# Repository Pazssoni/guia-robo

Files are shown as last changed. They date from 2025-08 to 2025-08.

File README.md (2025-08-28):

# BEMO - Bloco Educacional Modular Open-Source

Logo do BEMO

Bem-vindo ao repositório oficial do BEMO, um robô educacional de baixo custo, modular e de código aberto, projetado para democratizar o ensino de STEAM (Ciência, Tecnologia, Engenharia, Artes e Matemática) em escolas e ambientes de aprendizado.

Este projeto foi desenvolvido como um Trabalho de Conclusão de Curso em Engenharia de Computação no Instituto Federal Fluminense (IFF) por Bruno Alves Pesse Libardi e Maurício Santos Passoni.

**[Acesse o Guia Interativo Completo aqui!](https://guia-robo.vercel.app/)**

---

## 🎯 Sobre o Projeto

A robótica educacional é uma ferramenta poderosa, mas seu alto custo é uma barreira significativa para escolas públicas. O BEMO foi criado para ser uma solução acessível e replicável, com um custo de montagem aproximadamente 25 vezes menor que os kits comerciais de mercado.

### ✨ Principais Características
* ** baixo Custo:** Construído com componentes eletrônicos acessíveis, com um custo total estimado em menos de R$ 210,00.
* ** Modular:** Possui um sistema de módulos intercambiáveis (Sumô, Artista, Construtor LEGO) que se adaptam a diferentes atividades pedagógicas.
* ** Open-Source:** Todo o projeto, do hardware ao software, é de código aberto, permitindo que qualquer pessoa possa montar, modificar e aprimorar o BEMO.
* ** Impressão 3D:** O chassi e os módulos são projetados para serem fabricados em qualquer impressora 3D com filamento PLA, incentivando a autonomia e a cultura maker.
* ** Programação Acessível:** Utiliza a plataforma **mBlock**, baseada em blocos, que facilita o aprendizado de lógica de programação para iniciantes.

---

## 🛠️ Como Montar o seu Próprio BEMO

Para replicar o projeto, siga os passos abaixo.

### 1. Lista de Materiais (Bill of Materials)

A lista completa de componentes eletrônicos, parafusos e a bateria necessária pode ser encontrada no **[Guia de Montagem em PDF](./Guia_PDF/Guia_Montagem_BEMO.pdf)**, que está neste repositório.

### 2. Arquivos para Impressão 3D

Todas as peças do chassi e os módulos intercambiáveis estão disponíveis em formato `.STL` na pasta **`/Arquivos_Impressao_3D`** deste repositório.

* **Material Recomendado:** Filamento PLA
* **Configuração Sugerida:** Altura de camada de 0.2mm, com suportes ativados.

### 3. Guia de Montagem

A montagem do hardware é detalhada passo a passo em nossos guias:
* **Guia Interativo (Recomendado):** [https://guia-robo.vercel.app](https://guia-robo.vercel.app) - Inclui vídeos e uma experiência mais dinâmica.
* **Guia em PDF:** Disponível na pasta **`/Guia`**.

### 4. Configuração do Ambiente de Programação (mBlock)

1.  **Instale o mBlock:** Baixe a versão para PC no site oficial: [mblock.cc](https://mblock.cc/pages/downloads).
2.  **Adicione o Dispositivo:** Na aba "Dispositivos", procure e adicione o **"Arduino Nano"**.
3.  **Instale as Extensões:** No "Centro de Extensões", pesquise e adicione as duas extensões necessárias:
    * `Easy Motor Driver`
    * `TCRT5000 IR`
4.  **Comece a Programar!** As atividades práticas e os códigos de exemplo estão no Capítulo 7 dos guias (interativo e PDF).

---

## 📁 Estrutura do Repositório

* **/Arquivos_Impressao_3D:** Contém todos os arquivos `.STL` para imprimir o BEMO.
* **/Guia_PDF:** Contém a versão em PDF do guia completo de montagem e programação.
* **index.html:** Código-fonte do guia interativo online.
* **README.md:** Este arquivo que você está lendo.

---

## 📜 Citação

Se você utilizar este projeto em seu trabalho, por favor, cite-o da seguinte forma:

LIBARDI, B. A. P.; PASSONI, M. S. **BEMO (Bloco Educacional Modular Open-Source): um robô educacional de baixo custo para o ensino de STEAM.** Trabalho de Conclusão de Curso (Graduação em Engenharia de Computação) – Instituto Federal Fluminense, Bom Jesus do Itabapoana, 2025.

---

## 👨‍💻 Autores

* **Bruno Alves Pesse Libardi**
* **Maurício Santos Passoni**

Agradecemos o apoio dos nossos orientadores, Ianne Lima Nogueira e Anderson de Souza Lima.

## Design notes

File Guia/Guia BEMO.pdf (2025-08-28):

## Guia Completo do BEMO: Montagem, Programação e Exploração Criativa

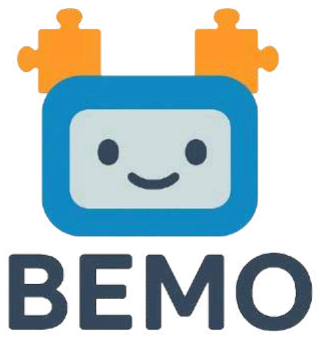
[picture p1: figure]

## Autores: Bruno Libardi e Maurício Passoni

### Prefácio: Uma Aventura no Mundo da Robótica

Bem-vindo ao fascinante universo da robótica! O guia que tem em mãos é mais do que um manual de instruções; é um convite para uma jornada de descoberta, criação e aprendizado. Ao longo das próximas páginas, será possível transformar um conjunto de peças impressas em 3D e componentes eletrônicos em um robô funcional e inteligente. Este processo foi desenhado para ser uma aventura gratificante, onde cada parafuso apertado e cada bloco de código encaixado representam um passo em direção a uma nova compreensão sobre como a tecnologia funciona.
E para começar nossa jornada, vamos conhecer nosso robô pelo nome: ele se chama BEMO! O nome é uma sigla para Bloco Educacional Modular Open-Source, que resume tudo o que ele representa: uma ferramenta de aprendizado baseada em blocos de programação, com peças que se encaixam e um projeto totalmente aberto para quem quiser montar e aprimorar.

Por que Robótica?
A robótica educacional é uma poderosa ferramenta que prepara jovens para um futuro cada vez mais tecnológico. Ensinar e aprender robótica vai muito além de construir e programar máquinas; trata-se de desenvolver habilidades fundamentais para o século XXI. Através de atividades práticas e envolventes, os participantes exercitam o raciocínio lógico, a capacidade de resolver problemas complexos, a criatividade para encontrar novas soluções e o trabalho em equipe para alcançar objetivos comuns. Ao construir este robô, os alunos não estão apenas "brincando", mas se engajando ativamente em conceitos de ciência, tecnologia, engenharia, artes e matemática (STEAM), preparando-se para os desafios do futuro de forma interativa.

Objetivos Deste Guia
Ao concluir a leitura e as atividades propostas neste guia, qualquer utilizador, seja professor ou aluno, será capaz de:

### 1. Montar o BEMO a partir de peças impressas em 3D e componentes

eletrônicos, compreendendo a função de cada parte.

### 2. Identificar e entender o papel dos componentes principais: o "cérebro"

(microcontrolador), os "músculos" (motores) e os "sentidos" (sensores).

### 3. Aprender os fundamentos da programação visual baseada em blocos

utilizando o software mBlock.

### 4. Executar missões práticas e desafios que darão vida, propósito e

personalidade ao BEMO.
Uma Nota para Professores e Alunos
Este guia foi criado com um princípio em mente: qualquer pessoa pode aprender robótica. Não é necessário nenhum conhecimento prévio em eletrônica, programação ou impressão 3D. Cada capítulo foi estruturado para apresentar os conceitos de forma clara e passo a passo. O erro não deve ser visto como um fracasso, mas como uma parte essencial do processo de "aprender fazendo" (learning by doing).

### 2 Encoraja-se a

experimentação, a curiosidade e a colaboração. Juntos, professores e alunos podem transformar este projeto numa experiência de aprendizado inesquecível.

Prefere Aprender com Vídeos? Conheça nosso Guia Interativo!

Para uma experiência de montagem ainda mais visual e detalhada, criamos um Guia Online Interativo. Além de todo o conteúdo que você encontra aqui, a versão online te dá acesso a vídeos tutoriais para as principais etapas, mostrando o passo a passo em ação.

Acesse a qualquer momento em: https://guia-robo.vercel.app

Conectando o BEMO à Sala de Aula: Uma Ferramenta para a BNCC

Professor, uma das maiores potências do BEMO é sua capacidade de se conectar a diferentes áreas do conhecimento, funcionando como uma ponte entre a teoria e a prática. Este robô não é apenas uma ferramenta para ensinar programação; ele foi pensado para desenvolver competências e habilidades previstas na Base Nacional Comum Curricular

(BNCC) de forma lúdica e interdisciplinar. Ao trabalhar com o BEMO, os estudantes são incentivados a exercitar o Pensamento Científico, Crítico e Criativo (Competência Geral 2) e a Cultura Digital (Competência Geral 5), aprendendo não apenas a consumir tecnologia, mas a criá-la.

Como Conectar as Matérias com as Atividades do Guia?

As atividades práticas propostas neste guia, especialmente com o uso dos módulos intercambiáveis, abrem portas para explorar conteúdos de diversas matérias. Aqui estão algumas ideias baseadas nas habilidades da BNCC:

- Matemática:
- Atividade Sugerida: Usar o "Módulo Artista Robótico" para desenhar figuras geométricas.
- Conexão com a BNCC: Os alunos aplicarão na prática conceitos de geometria, ângulos e plano cartesiano para programar os desenhos. Eles também podem usar álgebra para otimizar os códigos com laços e variáveis.
- Ciências da Natureza:
- Atividade Sugerida: Realizar um combate com o "Módulo Lutador de Sumô".
- Conexão com a BNCC: É a oportunidade perfeita para discutir e investigar conceitos de Física como força, atrito, torque e centro de gravidade de forma experimental.
- Ciências Humanas:
- Atividade Sugerida: Programar o robô para seguir uma rota desenhada em um mapa ou maquete.
- Conexão com a BNCC: Em Geografia, os alunos podem trabalhar com a elaboração e interpretação de mapas, usando o robô para representar trajetos ou fluxos.
- Linguagens:
- Atividade Sugerida: Criar desenhos e padrões artísticos com o "Módulo Artista Robótico".
- Conexão com a BNCC: Em Artes, os estudantes utilizam a programação como uma nova forma de expressão para produzir repertórios artísticos. Em Língua Portuguesa, podem ser incentivados a criar um "diário de bordo" do projeto, relatando os experimentos e desafios.

Esses são apenas pontos de partida. Encorajamos você, professor, a usar sua criatividade para integrar o BEMO aos seus planos de aula, transformando o aprendizado em uma experiência "mão na massa", engajadora e alinhada às demandas educacionais do século XXI.

### Antes de Começar: Checklist de Materiais e Ferramentas

Para garantir que a jornada de montagem seja fluida e sem interrupções, é fundamental preparar todos os componentes e ferramentas com antecedência. Utilize esta página como um checklist para organizar seu espaço de trabalho.

Componentes do BEMO

Esta é a lista completa de peças que darão vida, movimento e sentidos ao seu robô.

- Eletrônica Central:
- 1x Microcontrolador Arduino Nano V3.0
- 1x Placa de Expansão (Shield) Nano IO
- Sistema de Locomoção:
- 2x Motores DC com Caixa de Redução
- 2x Rodas com Pneu de Borracha
- 1x Roda Livre (Roda Boba / Caster Wheel)
- Sensores (Os Sentidos do Robô):
- 1x Sensor de Distância a Laser (VL53L0X)
- 1x Placa com 5 Sensores de Linha (TCRT5000)
- Controle e Energia:
- 1x Módulo Driver Ponte H Dupla (L9110S)
- 1x Bateria de Lítio-Íon 18650 (Pack 7.4V, 3300mAh)

- Conexão e Fixação:
- 17x Jumpers Fêmea-Fêmea
- 1x Jumper Macho-Fêmea
- 1x Jumper Macho-Macho (para solda no pino VIN)
- 12x Parafusos M3x6mm
- 4x Porcas M3
- Estrutura (Impressão 3D):
- 1x Chassi Principal Impresso em PLA
- Módulos Intercambiáveis (Básico, Sumô, etc.)

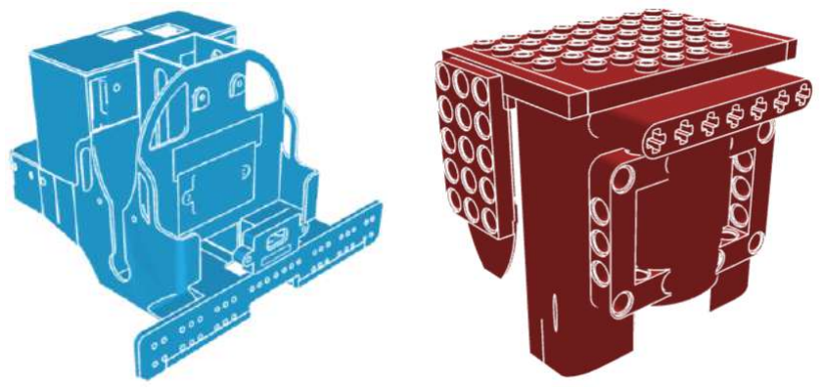
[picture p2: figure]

Ferramentas Necessárias

Estas são as ferramentas que você precisará para a montagem. Lembre-se que algumas delas devem ser manuseadas por um adulto ou supervisor.

- Ferramentas de Montagem:
- Chave Phillips (tamanho pequeno, compatível com parafusos M3)
- Alicate de bico fino (para remover suportes da impressão 3D)
- Equipamentos de Segurança:
- Óculos de Proteção (Obrigatório): Essencial durante a remoção dos suportes da peça impressa para proteger os olhos de fragmentos de plástico.
- Para o Supervisor (Uso Adulto):
- Ferro de Solda e Estanho (para a fixação dos fios nos motores e no pino VIN do shield)
- Estilete (para acabamento fino e remoção de rebarbas)
- Opcional (para Acabamento):
- Lixas d'água (granulação 240, 400 e 800) para um acabamento mais liso nas peças.

### Navegue pelos Capítulos

Capítulo 5: Personalidade e Função - Explorando os Módulos Intercambiáveis...

### Capítulo 1: Dando Vida ao Chassi - A Magia da Impressão 3D

A primeira etapa para construir o BEMO é fabricar o seu "esqueleto", o chassi. Utilizando a tecnologia de impressão 3D, é possível transformar um arquivo digital num objeto físico e funcional.

Obtendo os Arquivos
Para começar, é necessário baixar os arquivos de modelo 3D, eles estão no formato .STL. Estes arquivos contêm as informações geométricas que a impressora 3D utilizará para construir as peças camada por camada. O link para o download dos arquivos do chassi será disponibilizado a seguir.

Preparando para a Impressão
Antes de iniciar a impressão, algumas preparações são necessárias no software "fatiador" (slicer), como o Ultimaker Cura.
- Requisitos da Impressora: É preciso uma impressora 3D com uma mesa de impressão de dimensões suficientes para a peça do chassi. O material recomendado para este projeto é o filamento PLA (Ácido Polilático), por ser fácil de imprimir e seguro para ambientes educacionais.
Por que usamos o PLA?
Embora existam outros materiais como ABS e PETG, o PLA foi escolhido por ser o mais fácil e seguro de imprimir em qualquer impressora 3D, mesmo em modelos abertos e sem mesa aquecida, condições comuns em escolas. Ele oferece a resistência necessária para o robô e é biodegradável.
- Configurações do Fatiador: Para um bom equilíbrio entre velocidade e qualidade, recomenda-se uma altura de camada de 0.2 mm. Um ponto crucial é a ativação de suportes.

Pós-impressão: O Trabalho do Artesão

Após a conclusão da impressão, a peça não está pronta para uso imediato. A fase de pós-processamento é fundamental para garantir não apenas uma boa aparência, mas principalmente o encaixe correto dos componentes eletrônicos e mecânicos.
- Passo 1: Remoção dos Suportes
A peça impressa sairá da impressora com as estruturas de suporte ainda presas, semelhante ao que é visto na Imagem 1. A remoção deve ser feita com cuidado.
- Ferramentas: Utilize um alicate de bico fino ou uma pequena espátula para quebrar e remover os suportes maiores.
- Segurança: Este processo pode gerar pequenos fragmentos de plástico afiados. É altamente recomendado o uso de óculos de proteção para evitar acidentes. A remoção deve ser feita de forma lenta e controlada para não danificar a peça principal.
- Passo 2: Limpeza e Acabamento
É comum que a peça apresente pequenas rebarbas ou fios finos de plástico (conhecidos como "stringing"). Estes podem ser removidos cuidadosamente com um estilete (por um adulto) ou com os dedos.
- Passo 3 (Opcional): Lixamento para um Acabamento Superior
Este passo é opcional e recomendado caso você deseje obter uma aparência mais lisa e profissional para o seu robô, ou se notar que o encaixe de alguma peça está muito justo. O lixamento ajuda a remover as linhas de camada visíveis da impressão 3D e a realizar ajustes finos nas dimensões dos encaixes, garantindo que os componentes se acoplem perfeitamente.
- Técnica: Para o PLA, recomenda-se o lixamento úmido. Molhar a lixa e a peça com água ajuda a resfriar a superfície, evitando que o atrito excessivo derreta o plástico.
- Granulação: Inicie com uma lixa de granulação mais grossa (ex:
240) para remover as imperfeições maiores. Em seguida, avance para granulações mais finas (ex: 400, 800 ou superior) para obter uma superfície lisa. O objetivo é refinar a estética e corrigir pequenas imperfeições da impressão que possam dificultar o encaixe dos motores, sensores e placas.

### Capítulo 2: Os Primeiros Passos - Montando a Mobilidade

Com o chassi pronto, é hora de dar ao BEMO a capacidade de se mover. Neste capítulo, serão instalados os componentes responsáveis pela mobilidade: a roda livre e os motores.O Terceiro Ponto de Apoio
Para que o robô se equilibre e se mova suavemente, ele utiliza duas rodas motorizadas e um terceiro ponto de apoio. Este apoio é uma roda livre (também chamada de caster wheel ou esfera de apoio).
- Instalação: Localize os furos de montagem na parte inferior e frontal do chassi. Posicione a roda livre sobre os furos e fixe-a utilizando dois parafusos de tamanho apropriado com suas respectivas porcas. Aperte firmemente para que não haja folgas.

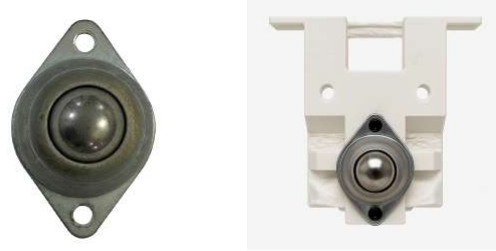
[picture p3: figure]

Instalando os "Músculos" - Os Motores DC
Os "músculos" do BEMO são os dois motores de corrente contínua (DC) com caixa de redução. A caixa de redução (a parte amarela visível na Imagem 4) diminui a velocidade do motor, mas aumenta sua força (torque), permitindo que o robô se mova com precisão e força.
- Encaixe: Insira cada motor nos seus respectivos suportes laterais no chassi. O design do chassi deve permitir um encaixe justo. Empurre os motores até o fim.
- Fixação: Se notar alguma folga, utilize os furos de fixação laterais para inserir pequenos parafusos que prenderão o motor firmemente contra o chassi. Um motor solto pode causar vibrações e imprecisão no movimento. A Imagem 4 mostra um motor já encaixado lateralmente.
- Atenção, Professor! Os fios elétricos precisam ser conectados aos terminais metálicos na parte traseira de cada motor. Esta conexão é mais robusta e confiável quando feita com solda. Recomenda-se que este passo seja realizado por um professor ou adulto com experiência em soldagem antes da aula, para garantir a segurança dos alunos e a qualidade da conexão elétrica.

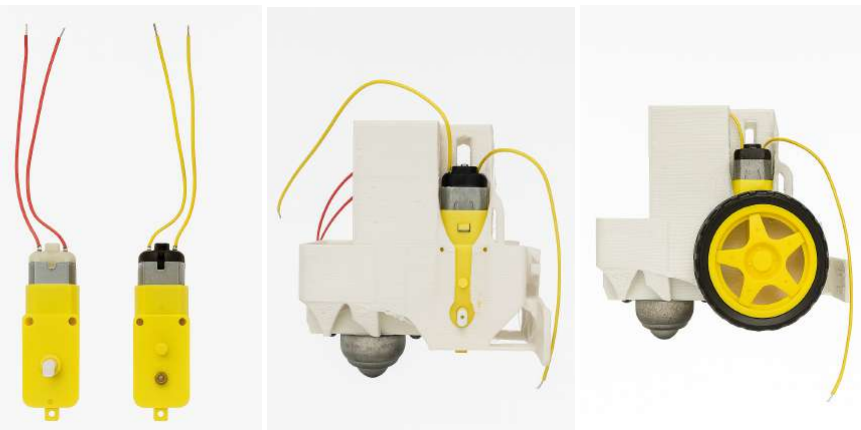
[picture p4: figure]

A Ponte para o Controle - Conectando a Ponte H
O cérebro do robô (Arduino) não consegue fornecer energia suficiente para mover os motores diretamente. Além disso, ele precisa de uma forma de dizer aos motores para girarem para frente ou para trás. A Ponte H resolve ambos os problemas.

O que é uma Ponte H?
Imagine a Ponte H como um conjunto de quatro interruptores inteligentes para cada motor. Ao combinar como estes interruptores são ligados ou desligados, a Ponte H pode direcionar a energia da bateria para fazer o motor girar no sentido horário ou anti-horário. É o componente que "traduz" os comandos de baixo sinal do Arduino em movimento de alta potência para os motores.9
- Conexão dos Motores: Antes de instalar a Ponte H no chassi, conecte os dois fios de cada motor aos terminais de saída da placa. Geralmente, estes terminais são identificados como OUT1 e OUT2 para o motor esquerdo, e OUT3 e OUT4 para o motor direito. A ordem exata determinará o sentido de rotação "padrão", mas isso pode ser corrigido posteriormente na programação.
- Instalação no Chassi: Após conectar os fios dos motores, encaixe a placa da Ponte H no local designado na parte frontal do robô. Os fios de entrada da Ponte H (que virão do Arduino) devem ficar acessíveis. A montagem nesta sequência — conectar os motores à Ponte H primeiro e depois fixá-la — é muito mais simples do que tentar conectar os fios com a placa já no lugar.

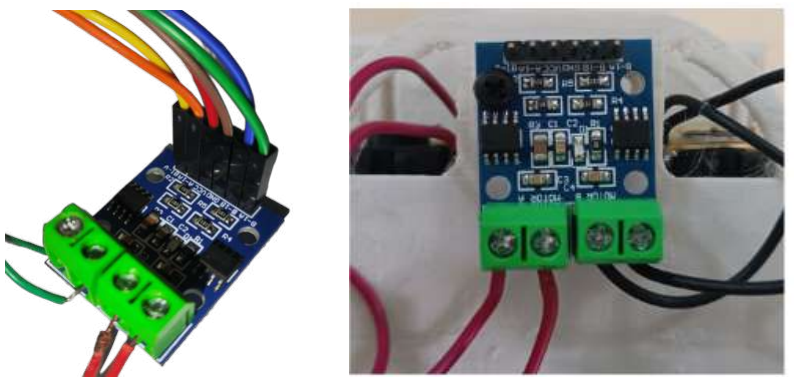
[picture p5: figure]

### Capítulo 3: O Cérebro da Operação - Instalando a Eletrônica Central

Agora que o robô tem um corpo e músculos, é hora de instalar o seu cérebro: o microcontrolador Arduino Nano e seu shield de expansão.

Conheça o Cérebro: O Arduino Nano
O Arduino é uma plataforma de prototipagem eletrônica de código aberto. A placa Arduino Nano é o "cérebro" do nosso robô. É um pequeno computador que pode ser programado para ler informações do ambiente através de sensores e controlar atuadores, como os motores, para interagir com o mundo físico.

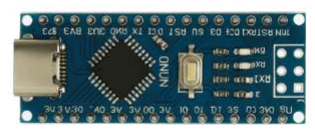
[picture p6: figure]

O Escudo Protetor e Conector: O Shield
Um "shield" é uma placa de circuito impresso que se encaixa sobre o Arduino para expandir suas capacidades. Neste projeto, o shield facilita enormemente a conexão de todos os sensores e da Ponte H, organizando as portas e fornecendo pinos de alimentação adicionais. Ele age como um sistema nervoso centralizado.

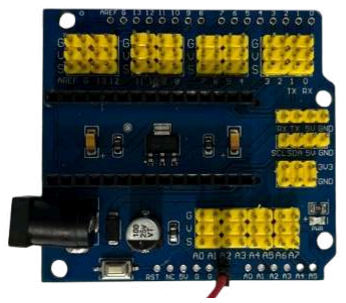
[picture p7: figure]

Além de facilitar as conexões, o Shield também é importante para a segurança do seu robô. Ele possui um regulador de tensão que garante a energia correta para os componentes e um diodo que protege tudo caso a bateria seja conectada ao contrário por engano.

Montagem do Cérebro
A montagem do conjunto principal é simples, mas requer cuidado.
- Alinhe cuidadosamente todos os pinos do Arduino Nano com os

soquetes | correspondentes | no | shield. | Pressione | firme | e
uniformemente até que o Nano esteja completamente encaixado, sem pinos tortos ou fora do lugar.

Preparação Crítica: Pré-cabeamento do Shield
Esta é uma das etapas mais importantes para garantir uma montagem final fácil e sem erros. Em vez de conectar os fios um a um com a placa já dentro do chassi apertado, todo o cabeamento será preparado agora. Esta abordagem transforma uma tarefa potencialmente frustrante em uma atividade de montagem organizada e didática.
- Utilizando a tabela de conexões abaixo, conecte um cabo jumper (fêmea-fêmea) em cada pino necessário no shield. É útil usar cabos de cores diferentes para cada grupo de função (ex: um conjunto de cores para o sensor de distância, outro para os sensores de linha, etc.).

Tabela de Conexões do Shield do Arduino Nano

Componente | Pino do Componente | Pino do Shield (Arduino Nano) | Função
Sensor de Distância VL53L0X | VIN | 5V | Alimentação do sensor (+5V)
| GND | GND | Terra (Referência 0V)
| SDA | A4 | Linha de Dados do barramento I²C
| SCL | A5 | Linha de Clock do barramento I²C
| XSHUT | D2 | Pino de controle (liga/desliga o sensor)
5 Sensores de Linha TCRT5000 | VCC (todos) | 5V | Alimentação dos sensores (+5V)

| GND (todos) | GND | Terra (Referência 0V)
| OUT S0 (Ext. Esq.) | D3 | Sinal do sensor 1 (digital)
| OUT S1 (Meia Esq.) | D4 | Sinal do sensor 2 (digital)
| OUT S2 (Centro) | D5 | Sinal do sensor 3 (digital)
| OUT S3 (Meia Dir.) | D6 | Sinal do sensor 4 (digital)
| OUT S4 (Ext. Dir.) | D7 | Sinal do sensor 5 (digital)
Ponte H (Controle Motores) | IN1 | D8 | Controle do motor esquerdo (sentido 1)
| IN2 | D9 | Controle do motor esquerdo (sentido 2)
| IN3 | D10 | Controle do motor direito (sentido 1)
| IN4 | D11 | Controle do motor direito (sentido 2)
| VCC | 5V | Alimentação da lógica da Ponte H
| GND | GND | Terra comum
- Atenção, Professor! O pino VIN do Arduino Nano (acessível no shield) será usado para alimentar a placa a partir da bateria, através da Ponte
H. Para isso, um fio deve ser soldado a este pino. Esta solda deve ser feita previamente por um profissional para garantir uma conexão segura e durável.

Com certeza. Estruturar o pré-cabeamento por etapas, com foco em cada componente, deixará o guia muito mais claro e didático, justificando a inclusão de imagens específicas para cada conexão. Utilizei a excelente estrutura do seu guia online para reescrever essa seção.

Etapa 1: Foco na Ponte H

Primeiro, localize os pinos no shield que controlarão os motores. Conecte os jumpers aos pinos D8, D9, D10 e D11 para o controle dos motores, e aos pinos 5V e GND para alimentar a lógica da Ponte H. Mantenha esses seis fios agrupados.

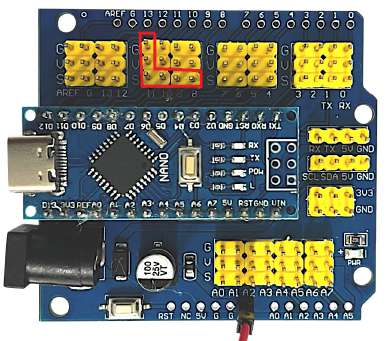
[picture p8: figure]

Etapa 2: Foco no Sensor de Distância

Agora, conecte os jumpers para o sensor de distância VL53L0X. Você precisará dos pinos A4 (SDA), A5 (SCL), D2 (XSHUT), e também de um pino 5V e GND. Agrupe esses cinco fios.

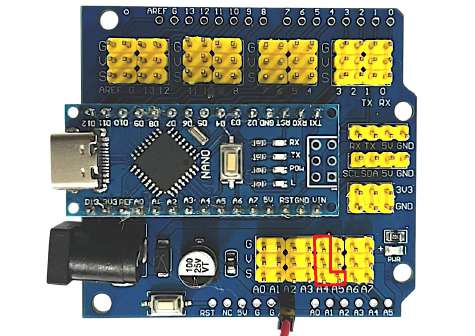
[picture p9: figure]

Etapa 3: Foco nos Sensores de Linha

Por último, prepare a conexão para a placa de sensores de linha TCRT5000. Conecte os jumpers aos cinco pinos de sinal, D3, D4, D5, D6 e D7. Conecte também um jumper a um p-ino 5V e outro a um pino GND, que serão compartilhados por todos os sensores da placa. Agrupe estes sete fios.

Instalação Final

Com o conjunto "cérebro + sistema nervoso" pronto, é hora de instalá-lo no chassi.
- Instalação: Encaixe o conjunto (Nano + Shield + cabos) no local designado dentro do chassi do robô.
- Organização dos Fios: Passe cuidadosamente os feixes de cabos pelos canais e aberturas internas do chassi, direcionando-os para a parte frontal. A Imagem 3 mostra o resultado esperado, com os conectores dos jumpers emergindo na frente, prontos para serem ligados aos sensores e à Ponte H no próximo capítulo.

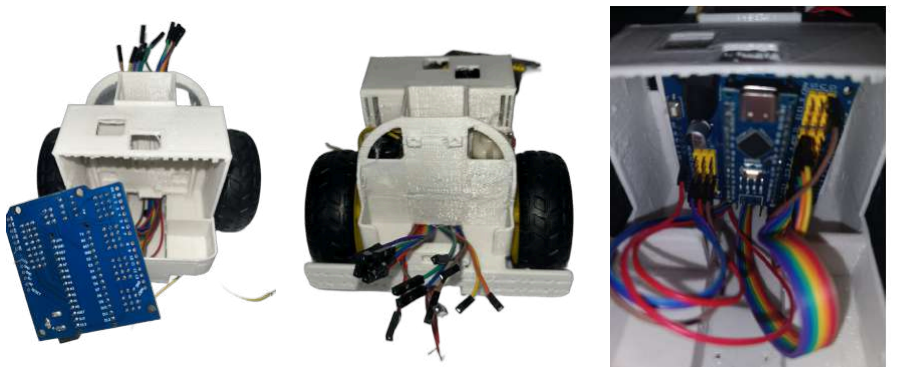
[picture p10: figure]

### Capítulo 4: Dando Sentidos ao Robô - Conexão de Sensores e Bateria

Com o cérebro instalado, o próximo passo é conectar os "sentidos" do robô. Estes sensores permitirão que ele perceba o mundo ao seu redor. A montagem será muito facilitada pelo pré-cabeamento realizado no capítulo anterior.

Os Olhos a Laser - Sensor de Distância VL53L0X
Este pequeno sensor é um dos sentidos mais precisos do BEMO. Ele funciona como uma trena a laser, medindo distâncias com alta exatidão.
- Como Funciona: O sensor emite um pulso de laser infravermelho (invisível e seguro) e mede o tempo que a luz leva para bater num objeto e retornar. Esse "tempo de voo" é usado para calcular a distância.

### 13 A distância é calculada pela fórmula

d=(c×t)/2, onde d é a distância, c é a velocidade da luz e t é o tempo de ida e volta do pulso de laser.
- Instalação: Encaixe o módulo do sensor VL53L0X no seu suporte específico na parte frontal do chassi.
- Conexão: Pegue o grupo de fios que foi preparado para este sensor no capítulo anterior e conecte cada jumper ao pino correspondente no módulo: VIN, GND, SDA, SCL e XSHUT.

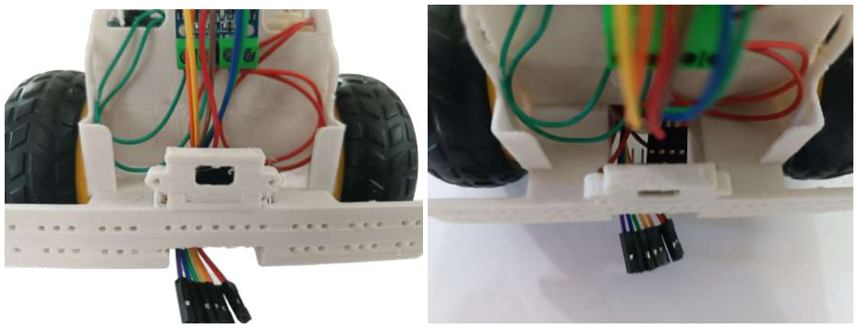
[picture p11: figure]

Ligando os Motores ao Cérebro
Agora, os sinais de controle do cérebro serão conectados à Ponte H, que por sua vez comanda os motores.
- Conexão: Localize o grupo de jumpers destinados à Ponte H. Conecte os pinos de controle IN1, IN2, IN3 e IN4 aos pinos correspondentes na Ponte H. Conecte também os pinos de alimentação da lógica da ponte, VCC (para o 5V do shield) e GND.

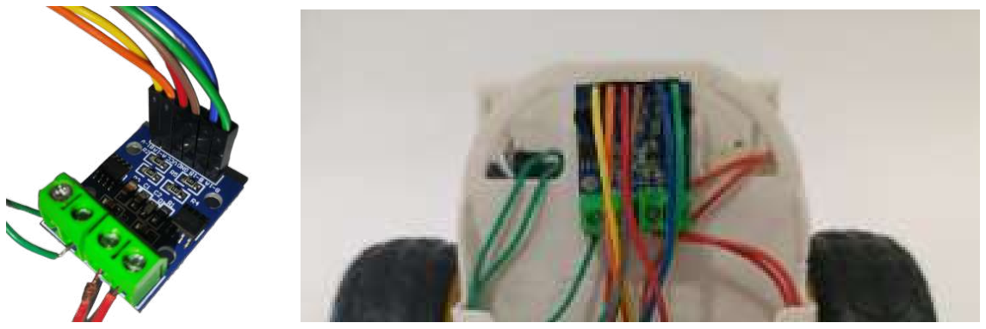
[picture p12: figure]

Sentindo o Chão - Placa de Sensores TCRT5000
Esta placa é o que permite ao robô seguir uma linha. Ela possui cinco pares de emissores e receptores de infravermelho.
- Como Funciona: Cada um dos cinco sensores TCRT5000 emite luz infravermelha para o chão. Uma superfície clara (como papel branco) reflete muita luz de volta para o sensor, enquanto uma superfície escura (como fita isolante preta) absorve a maior parte da luz. Ao ler quais sensores estão recebendo reflexo, o robô sabe onde a linha está.
- Montagem:

### 1. Primeiro, fixe a placa de sensores ao seu suporte/cobertura de

plástico, que ajuda a protegê-la e a direcionar o foco dos sensores.

### 2. Conecte os jumpers (VCC, GND, e os sinais de S0 a S4) aos pinos

correspondentes na placa de sensores.

### 3. Por fim, fixe o conjunto completo (placa + suporte) na estrutura

frontal do robô, que se assemelha a um para-choque, utilizando pequenos parafusos e porcas.

A Fonte de Energia - Instalando a Bateria
O último passo da montagem é dar energia ao robô.
- Conexão: Conecte o cabo da bateria aos terminais de alimentação principais da Ponte H (geralmente marcados como V+ e GND ou 12V e GND). É a partir daqui que a energia fluirá para os motores e, através do fio soldado no VIN, para o Arduino.
- Instalação: Coloque a bateria no seu compartimento na parte traseira do robô. Feche o compartimento com a tampa de encaixe.

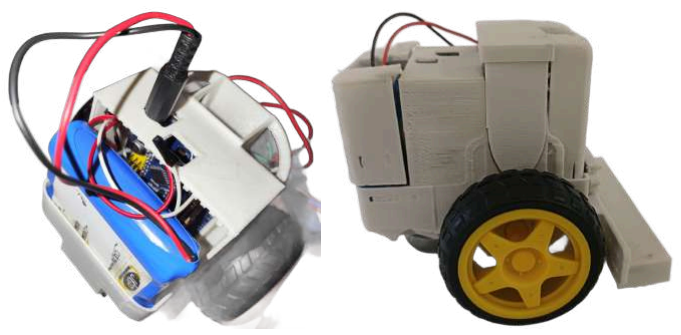
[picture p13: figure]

### Capítulo 5: Personalidade e Função - Explorando os Módulos Intercambiáveis do BEMO

Uma das características mais interessantes deste robô é sua capacidade de se adaptar a diferentes tarefas através de módulos intercambiáveis. Estes módulos são como "ferramentas" ou "chapéus" que se encaixam na parte central do chassi, alterando a aparência e a função do robô. Esta modularidade é uma excelente porta de entrada para a criatividade e para projetos interdisciplinares.

Um Robô, Várias Missões
O encaixe dos módulos é simples: basta posicioná-los sobre a área central do robô, cobrindo a fiação e o cérebro eletrônico. Cada módulo abre um novo leque de possibilidades.
- Módulo 1: A Carcaça Básica
Este é o módulo padrão. Sua função principal é proteger os componentes eletrônicos e a fiação exposta na parte frontal, dando ao robô um acabamento limpo e robusto. É ideal para as primeiras atividades de programação e movimento.

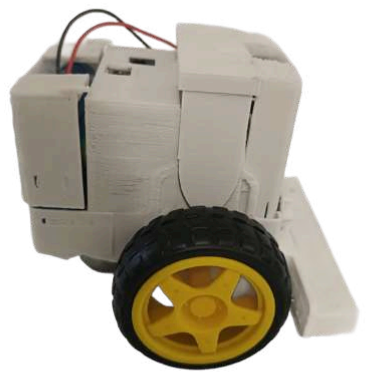
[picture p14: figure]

- Módulo 2: O Lutador de Sumô
Este módulo adiciona uma rampa ou pá na frente do robô. Ele foi projetado para competições de sumô de robôs, onde o objetivo é encontrar e empurrar o robô oponente para fora de uma arena circular. Este módulo permite explorar conceitos de Física, como força, torque, centro de gravidade e atrito.

- Módulo 3: O Construtor LEGO
Com encaixes compatíveis com peças LEGO Technic e System, este módulo transforma o robô numa plataforma de construção. Os alunos podem usar sua criatividade para construir estruturas, garras, catapultas ou qualquer outra coisa que imaginarem, integrando o mundo da robótica com o universo LEGO. Este módulo é perfeito para projetos de Engenharia e Design.

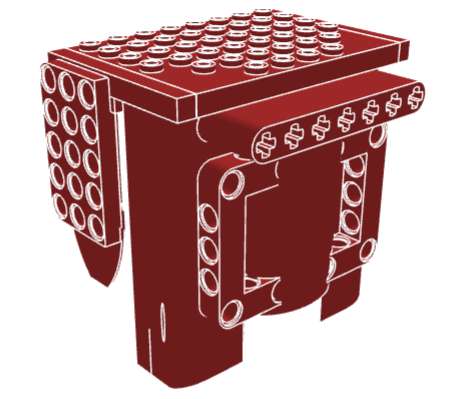
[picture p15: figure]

- Módulo 4: O Artista Robótico
Este módulo possui um suporte ajustável para prender uma caneta, um lápis ou um marcador. Com ele, o robô se transforma num "plotter" móvel, capaz de desenhar no papel. Os alunos podem programá-lo para desenhar formas geométricas, escrever letras ou criar padrões complexos. É uma forma fantástica de conectar a programação com a Arte e a Matemática (geometria de coordenadas).

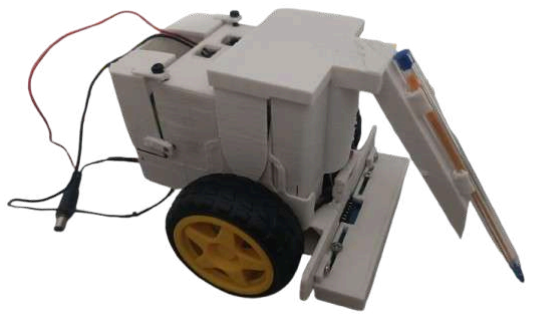
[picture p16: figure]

### Capítulo 6: A Linguagem dos Blocos - Programando com mBlock

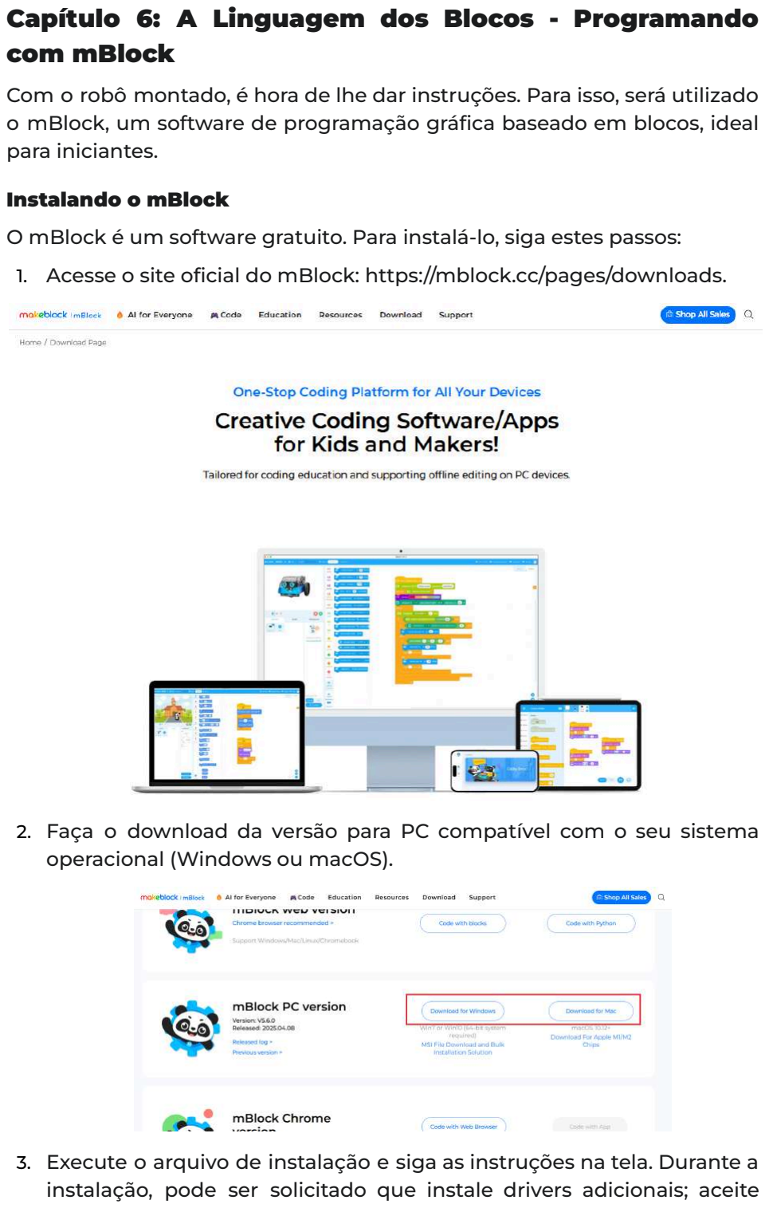
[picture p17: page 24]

Com o robô montado, é hora de lhe dar instruções. Para isso, será utilizado o mBlock, um software de programação gráfica baseado em blocos, ideal para iniciantes.

Instalando o mBlock
O mBlock é um software gratuito. Para instalá-lo, siga estes passos:
1. Acesse o site oficial do mBlock: https://mblock.cc/pages/downloads.

### 2. Faça o download da versão para PC compatível com o seu sistema

operacional (Windows ou macOS).

### 3. Execute o arquivo de instalação e siga as instruções na tela. Durante a

instalação, pode ser solicitado que instale drivers adicionais; aceite

para garantir a comunicação com o Arduino.

### 4. Como alternativa, é possível usar a versão web do mBlock, mas para

isso é necessário instalar um pequeno programa chamado mLink, também disponível no site, que permite que o navegador se comunique com o robô.

Primeiro Contato com a Interface
Ao abrir o mBlock, a interface é dividida em três áreas principais:

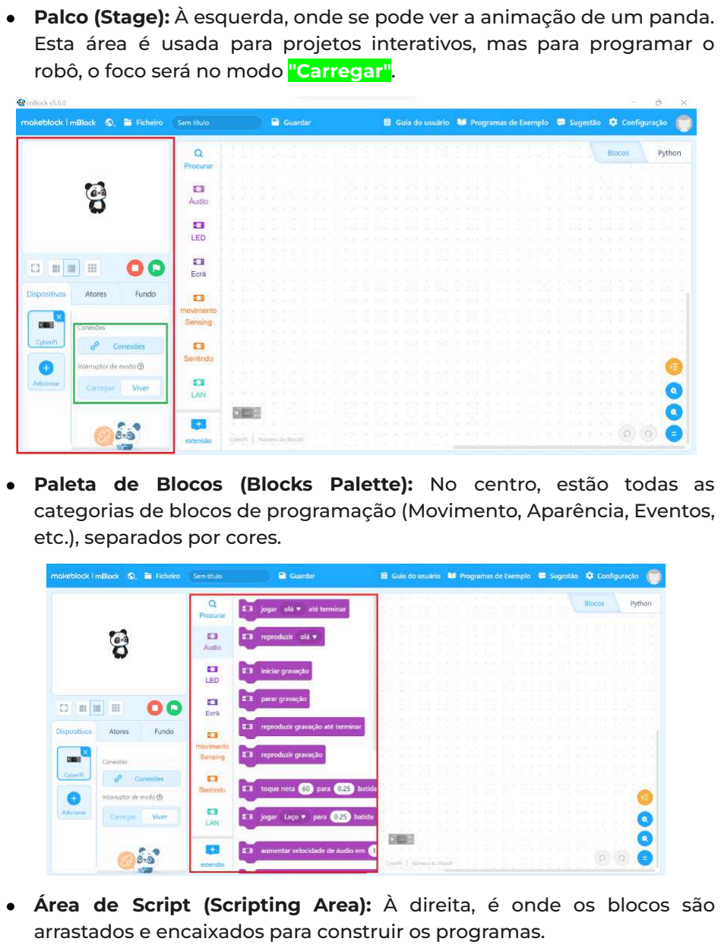
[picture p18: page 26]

- Palco (Stage): À esquerda, onde se pode ver a animação de um panda. Esta área é usada para projetos interativos, mas para programar o robô, o foco será no modo "Carregar".
- Paleta de Blocos (Blocks Palette): No centro, estão todas as categorias de blocos de programação (Movimento, Aparência, Eventos, etc.), separados por cores.
- Área de Script (Scripting Area): À direita, é onde os blocos são arrastados e encaixados para construir os programas.

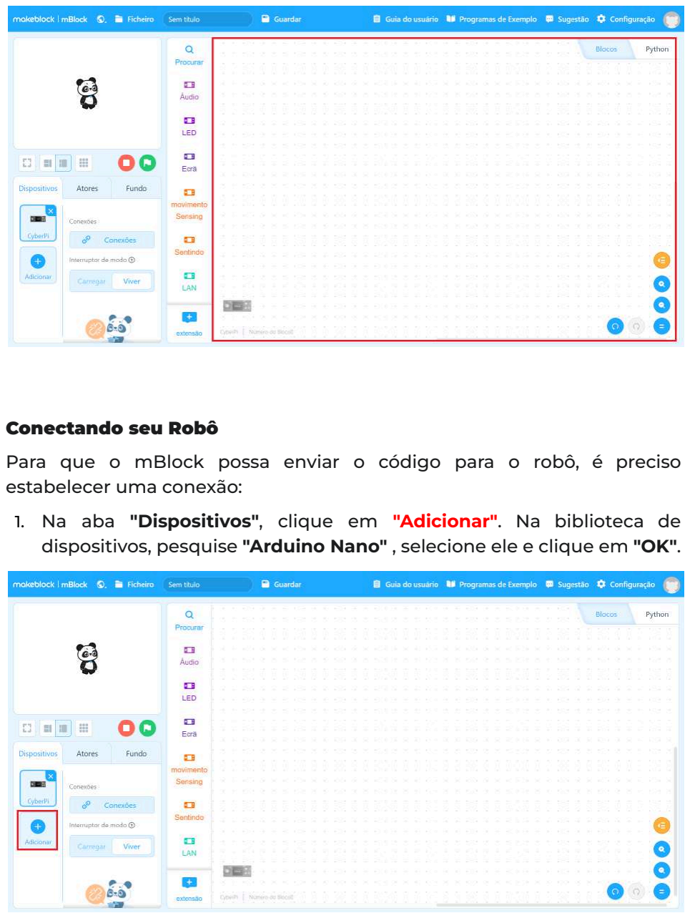
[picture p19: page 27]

Conectando seu Robô
Para que o mBlock possa enviar o código para o robô, é preciso estabelecer uma conexão:

### 1. Na aba "Dispositivos", clique em "Adicionar". Na biblioteca de

dispositivos, pesquise "Arduino Nano" , selecione ele e clique em "OK".

2. Conecte o robô ao computador usando o cabo USB.

### 3. Vá ao menu "Conectar" e selecione a porta serial correta (geralmente

algo como COM3 no Windows ou /dev/tty.usbserial no macOS), marque a opção para aparecer todas as portas.

4. No canto inferior direito, existem dois modos: Ao Vivo (Live) e Carregar (Upload). O modo "Ao Vivo" executa o código enquanto o robô está conectado ao PC. O modo "Carregar" envia o programa para a memória do Arduino, permitindo que o robô funcione de forma autônoma, desconectado do computador. Para as atividades deste guia, será usado o modo Carregar.

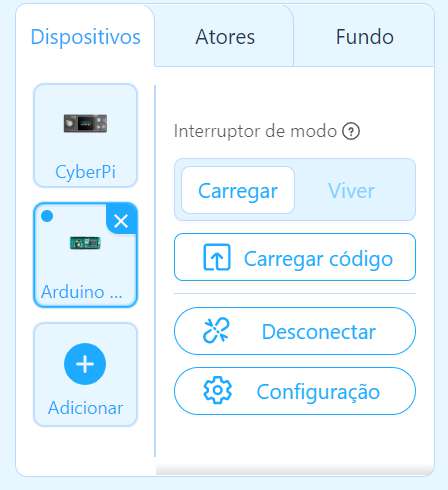
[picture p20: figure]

As Ferramentas Especiais: Instalando Extensões
O robô utiliza componentes (como a Ponte H e a placa de sensores específica) que não são reconhecidos nativamente pelo mBlock. Para adicionar os blocos de controle para estes componentes, é necessário instalar extensões.
1. Na parte inferior da paleta de blocos, clique no botão azul "+ extensão".

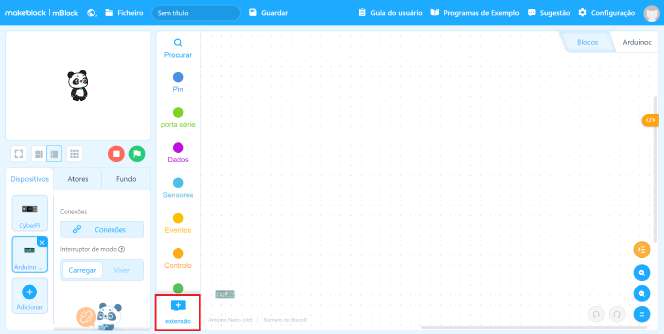
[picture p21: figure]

### 2. Na janela "Centro de Extensões", clique em "Extensões do Dispositivo"

na parte superior e pesquise "Easy Motor Driver".

### 3. Clique em adicionar e depois repita o mesmo processo, mas agora

pesquisando "TCRT5000".

4. Agora as duas extensões necessárias para este robô: "Easy motor Driver" e "TCRT5000 IR" já estão instaladas!

Conhecendo seus Novos Blocos
Após instalar as extensões, novas categorias de blocos aparecerão na paleta. Estes são os blocos que permitirão controlar o robô. A tabela abaixo serve como um guia de referência rápido para os blocos mais importantes.

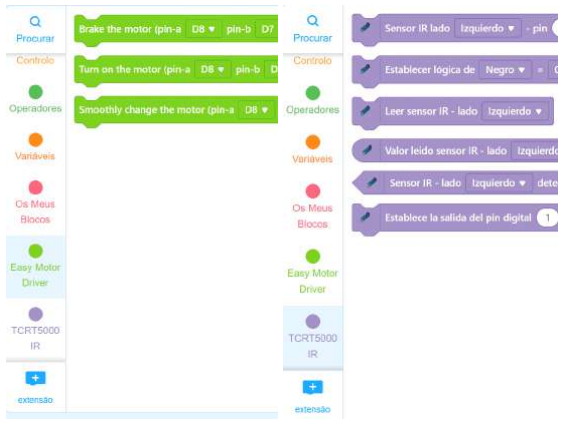
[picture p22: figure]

Tabela de Blocos Essenciais e Suas Funções

Categoria da Extensão | Imagem do Bloco (Descrição Textual) | Descrição da Função
Easy motor control | Bloco "mover para frente com potência % por seg" | Move os dois motores para frente na velocidade e duração especificadas.
Easy motor control | Bloco "virar à direita com potência % por seg" | Faz o robô girar sobre seu próprio eixo para a direita.
Easy motor control | Bloco "parar de mover" | Desliga ambos os motores, fazendo o robô parar.
Easy motor control | Bloco "definir velocidade do motor [M1] para %" | Controla a velocidade de um único motor (M1=Esquerdo, M2=Direito).
Sensor TCRT5000 | Bloco "sensor de linha detecta preto?" | Bloco condicional (retorna verdadeiro ou falso). Ideal para ser usado em blocos Se.
Sensor TCRT5000 | Bloco "leitura do sensor de linha" | Bloco de relatório (retorna um valor, ex: 0 para branco, 1 para preto).

### Capítulo 7: Missão Aceita! - Atividades Práticas Guiadas

Agora é a hora da verdade: dar vida ao robô com programação! As atividades a seguir foram projetadas para introduzir conceitos de programação de forma gradual e divertida. Para cada atividade, o código será apresentado em blocos, com comentários explicando cada passo.

Planejando sua Aula: Duração da Bateria Antes de começar, é útil saber quanto tempo seu robô pode operar. A tabela abaixo mostra a autonomia média estimada da bateria (3300 mAh) com base em testes práticos, ajudando você a planejar suas atividades.

Cenário de Uso: | Atividade Típica: | Consumo Médio Estimado: | Autonomia Contínua: (Aprox.)
Baixo Esforço | Robô ligado, mas com motores em repouso. | 150 mA | 20 horas
Esforço Moderado | Seguir linha, desenhar, movimento contínuo em superfície plana. | 550 mA | 6 horas
Alto Esforço | Competição de sumô, empurrar objetos, subir rampas. | 1550 mA | 2 horas

Atividade 1: Dança Robótica (Frente e Trás)

- Objetivo: Uma atividade simples para verificar se os motores, a Ponte H e a comunicação com o mBlock estão funcionando corretamente. É o "Olá, Mundo!" da robótica.
- Extensões: Para que o mBlock possa controlar os motores do robô, precisamos adicionar um conjunto de blocos customizados, chamado de "extensão". As extensões funcionam como plugins que ensinam o mBlock a se comunicar com componentes de hardware que não são padrão. Para esta atividade, é essencial ter a extensão "Easy Motor Driver" instalada, pois é ela que fornece os blocos Turn on the motor.
- Lógica: O programa cria um ciclo de movimento contínuo e sem pausas. Como o robô possui dois motores independentes (esquerdo e direito), é necessário utilizar um bloco de comando para cada um deles. O código primeiro instrui ambos os motores a se moverem para trás com 60% de sua potência durante 2 segundos. Imediatamente após, a direção é invertida, e os dois motores são acionados para frente, também com 60% de potência, por mais 2 segundos. Este ciclo se repete indefinidamente, fazendo o robô "dançar" para frente e para trás.
- Código em Blocos (conforme a imagem):
1. Comece com o bloco de evento quando o Arduino iniciar.
2. Adicione um laço repetir para sempre.

### 3. Dentro do laço, adicione dois blocos Turn on the motor para

acionar os motores | (pinos D8/D9 e D10/D11) | com | speed | de
-60%.
4. Insira um bloco esperar 2 segundo(s).

### 5. Adicione novamente dois blocos Turn on the motor para os

mesmos pinos, mas desta vez com speed de 60%.
6. Finalize o ciclo com outro bloco esperar 2 segundo(s).
- Para Carregar: Conecte o robô, selecione o modo "Carregar" e clique no botão "Carregar para o dispositivo". Após o carregamento, o robô começará a executar a dança.

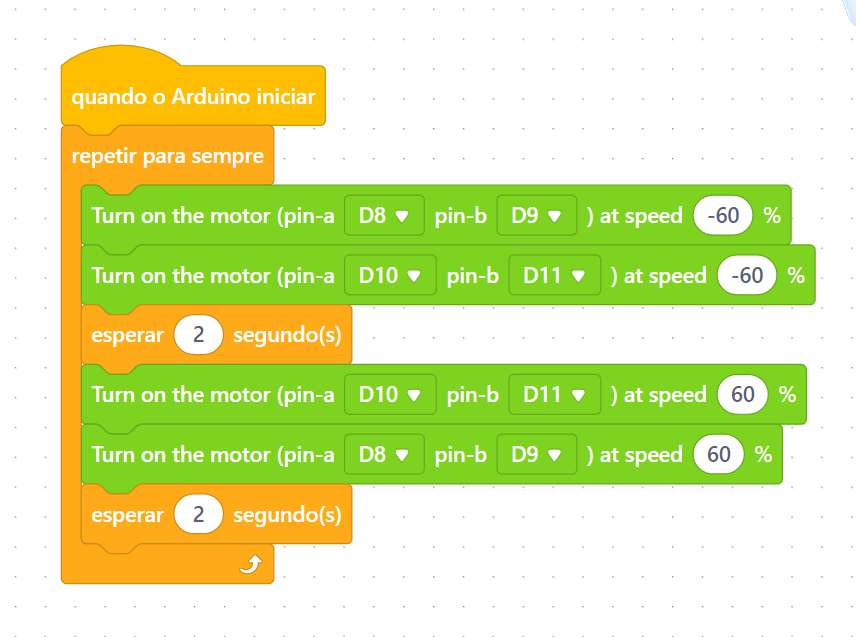
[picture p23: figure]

Atividade 2: O Desafio do Quadrado (Navegação Geométrica)

- Objetivo: Introduzir o conceito de movimentos sequenciais e controlados por tempo para realizar uma tarefa geométrica. Esta atividade também ensina uma lição fundamental em engenharia: a calibração.
- Extensões: Esta atividade utiliza os mesmos blocos de controle de movimento da atividade anterior. Portanto, é necessário que a extensão "Easy Motor Driver" esteja instalada e ativa no seu projeto mBlock
- Lógica: O programa instrui o robô a repetir exatamente 4 vezes a sequência de movimentos para formar os lados e cantos de um quadrado. Em cada repetição, o robô primeiro anda em linha reta por 2 segundos, com ambos os motores a 50% de potência. Em seguida, para criar um canto de 90 graus, ele realiza um giro sobre seu próprio eixo: o motor esquerdo vai para frente e o direito para trás, por um tempo calibrável de 0.8 segundos. Após completar os quatro lados, o laço termina e o robô executa um comando de freio para parar completamente.
- Momento de Descoberta - Calibração: O robô provavelmente não fará um quadrado perfeito na primeira tentativa. O tempo necessário para virar exatamente 90 graus (no código, 0.8 segundos) não é um valor fixo; ele depende do nível da bateria, da superfície do chão e de pequenas variações mecânicas. Os alunos devem ser incentivados a experimentar com este valor — aumentando-o ou diminuindo-o — até que o robô faça uma curva precisa de 90 graus. Este processo de ajuste fino é a calibração, uma prática comum e essencial em robótica e engenharia.
- Código em Blocos (conforme a imagem):
1. Comece com o bloco de evento
Quando o Arduino iniciar.
2. Adicione um laço
repetir 4 vezes.
3. Dentro do laço, para andar para frente, adicione dois blocos Turn on the motor com speed de 50%, seguidos por um bloco esperar 2 segundo(s).
4. Ainda dentro do laço, para virar à direita, adicione um bloco
Turn on the motor | (motor esquerdo) com | speed de 50% | e
outro (motor direito) com | speed de -50%, seguidos por um
bloco esperar 0.8 segundo(s).
5. Fora e após o laço, adicione dois blocos Brake the motor para parar o robô.

Atividade 3: Parada na Linha (Detecção de Borda)

- Objetivo: Introduzir o uso de um sensor infravermelho (IR) para detectar uma mudança de superfície (de claro para escuro) e tomar uma decisão com base nessa leitura. É um teste fundamental para validar o funcionamento do sensor de linha.
- Extensões: Esta atividade combina movimento e leitura de sensor, exigindo duas extensões diferentes. Você precisará da extensão "Easy Motor Driver" para controlar os motores (blocos Turn on the
motor | e | Brake the motor) e também da extensão "TCRT5000 IR"
para ler os dados do sensor de linha (bloco Sensor IR).
- Preparação: Crie uma área de teste com uma superfície clara (branca) e desenhe uma linha preta larga com fita isolante. O robô começará na parte clara e se moverá em direção à linha.
- Lógica: Este programa transforma o robô em um detector de borda e ensina conceitos essenciais da programação.

### 1. Configuração Inicial: Primeiro, o código define qual sensor

será utilizado (o da esquerda, no pino 5). Em seguida, os blocos "Establecer lógica" criam um "dicionário" para o robô. Como o sensor só entende sinais numéricos (0 ou 1), esses blocos traduzem os sinais: sempre que o sensor ler 0, o programa entenderá como "Branco"; sempre que ler 1, entenderá como "Negro". Isso torna o resto do código muito mais intuitivo.

### 2. Tomada de Decisão: Após a configuração, o robô entra em um

laço infinito (repetir para sempre). A cada instante, ele se pergunta: "O sensor está detectando a cor Branco?".
■ Se a resposta for SIM, a condição "então" é ativada, e os dois motores são acionados para mover o robô para frente.
■ Se a resposta for NÃO (o que significa que ele detectou a cor Negro), a condição "senão" é ativada, e os dois motores recebem um comando de freio, parando o robô imediatamente.
- Código em Blocos (conforme a imagem):
1. Comece com o bloco de evento Quando o Arduino iniciar.

### 2. Use o bloco Sensor IR lado para configurar qual sensor será

usado (lado Izquierdo no pino 5).
3. Use os blocos | Establecer lógica de Negro | para | = 1 | e
Establecer lógica de Blanco para = 0.
4. Adicione um laço repetir para sempre.
5. Dentro do laço, insira um bloco se/senão.

### 6. Na condição do se, use o bloco Sensor IR - lado Izquierdo

detecta Blanco.
7. Dentro do | se, adicione dois blocos | Turn on the motor com
speed de -100%.

### 8. Dentro do senão, adicione dois blocos Brake the motor para

parar o robô.

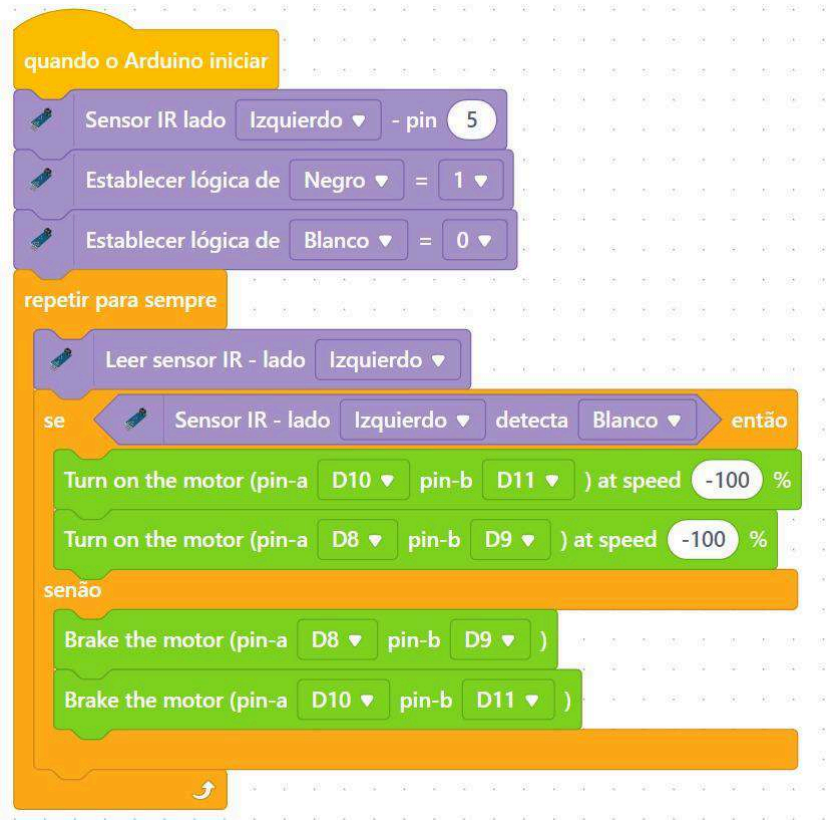
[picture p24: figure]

CAPÍTULO 8: MISSÃO CUMPRIDA! E AGORA?

Parabéns, explorador!

Se você chegou até aqui, você transformou um conjunto de peças e um punhado de ideias em um robô funcional e programado por você. Você montou, conectou, testou, provavelmente errou, consertou e, o mais importante, aprendeu a cada passo do caminho. Este é o coração da robótica e do movimento maker: aprender fazendo.

O seu BEMO agora está vivo, mas a jornada de vocês está apenas começando. As atividades deste guia foram os primeiros passos, projetados para ensinar os fundamentos e despertar sua curiosidade. Mas o verdadeiro potencial do BEMO está nas suas mãos.

O que vem a seguir?

- Experimente e Modifique: Volte aos códigos das atividades. O que acontece se você mudar os valores de velocidade? E os tempos de espera? Tente criar novos movimentos para a "Dança Robótica" ou programar o "Artista Robótico" para desenhar suas iniciais.
- Explore os Sensores: Nós usamos apenas um sensor de linha na última atividade. Como você poderia usar os outros quatro para criar um seguidor de linha ainda mais inteligente e rápido?
- Crie Seus Próprios Desafios: Use o "Módulo de Sumô" para organizar um campeonato com seus amigos. Crie um labirinto e programe o BEMO para encontrar a saída.

Este guia foi o mapa, mas o território a ser explorado é infinito. Continue curioso, continue criando e continue compartilhando o que você aprender. O BEMO não é apenas um projeto que você concluiu; é uma plataforma para todas as suas futuras invenções.

A aventura no mundo da robótica está apenas começando!

ANEXO II - QUESTIONÁRIOS DE AVALIAÇÃO

QUESTIONÁRIOS PRÉ E PÓS-TESTE - AVALIAÇÃO DO BEMO

PRÉ-TESTE – DOCENTES

Identificação:

Área de atuação docente:

- Linguagens
- Matemática
- Ciências da Natureza
- Ciências Humanas
- Educação Especial / Atendimento Educacional Especializado
- Outras: _______

Nível de ensino com que atua:

- Ensino Fundamental
- Ensino Médio
- Técnico Integrado
- Superior
- EJA
- Outros: _______

Você já teve contato com robótica educacional antes? → ( ) Sim / ( ) Não / ( ) Pouco contato

Por favor, leia cada uma das afirmações abaixo e indique o seu nível de concordância, selecionando o número que melhor representa sua opinião, conforme a seguinte escala:

1 = Discordo totalmente | 2 = Discordo | 3 = Neutro | 4 = Concordo | 5 = Concordo totalmente
1. Tenho familiaridade com conceitos básicos de robótica educacional.
2. Já utilizei robôs ou kits de automação em atividades pedagógicas.
3. Entendo o que é Arduino e como ele pode ser utilizado na educação.
4. Já trabalhei com sensores ou atuadores em sala de aula.
5. Conheço o ambiente de programação mBlock ou similares (ex: Scratch, Tinkercad).
6. Estou curioso(a) para conhecer novas ferramentas tecnológicas para o ensino.

7. Acredito que a robótica pode ser aplicada em qualquer área do conhecimento.
8. Considero importante incluir atividades práticas com tecnologia na escola pública.
9. Acredito que os alunos se engajam mais em atividades que envolvam o uso de ferramentas praticas, como os robôs.
10. Estou disposto(a) a adaptar minha prática docente se a proposta for viável.
11. Me sinto confiante para aprender a utilizar um robô educacional.
12. Tenho facilidade em lidar com tecnologias digitais no meu cotidiano profissional.
13. 13. Tenho familiaridade com programação.
14. Consigo imaginar formas de aplicar a robótica nos meus planos de aula.
15. Utilizo a metodologia STEAM em minhas aulas.

Perguntas Abertas

- Qual sua experiência prévia (se houver) com robótica ou programação?
- O que você espera aprender ou experimentar nesta oficina?

PÓS-TESTE – DOCENTES

Identificação:

Área de atuação docente:

- Linguagens
- Matemática
- Ciências da Natureza
- Ciências Humanas
- Educação Especial / Atendimento Educacional Especializado
- Outras: _______

Nível de ensino com que atua:

Ensino Fundamental

- Ensino Médio
- Técnico Integrado
- Superior
- EJA
- Outros: _______

Por favor, leia cada uma das afirmações abaixo e indique o seu nível de concordância, selecionando o número que melhor representa sua opinião, conforme a seguinte escala:

1 = Discordo totalmente | 2 = Discordo | 3 = Neutro | 4 = Concordo | 5 = Concordo totalmente
1. A atividade atendeu às minhas expectativas.
2. O tempo da oficina foi adequado para explorar o robô.
3. A proposta foi bem organizada e clara.
4. A metodologia utilizada facilitou o meu aprendizado.
5. A participação prática foi importante para compreender o funcionamento do robô.
6. O robô é adequado para uso com alunos do ensino fundamental ou médio.
7. A montagem do robô foi simples e viável para ambientes escolares.
8. O uso do mBlock facilitou o entendimento da lógica de programação.
9. Os materiais pedagógicos (tutoriais, roteiros) são claros e acessíveis.
10. O robô apresentou bom funcionamento durante a oficina.
11. Me sinto mais motivado(a) para usar robótica em sala de aula.
12. Acredito que a proposta pode ser adaptada à minha área de ensino.
13. Identifico potencial interdisciplinar no uso deste robô.
14. Vejo viabilidade de replicar essa proposta em escolas públicas.
15. Pretendo explorar ou sugerir o uso de robótica educacional em minha prática docente.

16. Acredito que a robótica tenha potencial de impactar diretamente o processo de ensino aprendizagem do aluno.

Perguntas Abertas
- O que você aprendeu de mais relevante durante a oficina?
- Que sugestões você daria para melhorar a proposta?
- Como imagina aplicar essa tecnologia no seu contexto educacional?

PRÉ-TESTE – DISCENTES

Identificação

- Idade: ____
- Gênero: ( ) Feminino ( ) Masculino ( ) Outro
- Ano escolar: ____

Por favor, leia cada uma das afirmações abaixo e indique o seu nível de concordância, selecionando o número que melhor representa sua opinião, conforme a seguinte escala:

1 = Discordo totalmente | 2 = Discordo | 3 = Neutro | 4 = Concordo | 5 = Concordo totalmente
1. Sei o que é um robô e para que ele pode ser usado.
2. Já montei algum tipo de robô.
3. Já usei Arduino, ou outro microcontrolador em alguma atividade.
4. Já tive contato com sensores (ex: distância, luz, giroscópio, infravermelho).
5. Já usei algum ambiente de programação visual (ex: Scratch, mBlock).
6. Me interesso por aprender robótica e automação.
7. Acho divertido trabalhar com tecnologia em sala de aula.
8. Costumo me sentir disperso(a) em aulas teóricas e expositivas.
9. Tenho vontade de criar meus próprios projetos com robôs.
10. A robótica é uma área que combina com minha personalidade.
11. Acredito que o uso de robôs pode ajudar na aprendizagem de outras disciplinas.
12. Me sinto capaz de aprender a programar um robô com ajuda.
13. Consigo acompanhar bem explicações sobre lógica de programação.
14. Tenho facilidade em aprender coisas novas com tecnologia.
15. Acredito que posso usar a programação para resolver problemas reais.
16. Estou animado(a) para participar da oficina com o robô.
17. Aprendo mais com exemplos práticos do que apenas com teoria

Perguntas Abertas

- Já teve alguma experiência com robótica ou kits eletrônicos? Qual?
- O que você espera aprender ou fazer nesta oficina?

PÓS-TESTE – DISCENTES

Identificação

- Idade: ____
- Gênero: ( ) Feminino ( ) Masculino ( ) Outro
- Ano escolar: ____

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

1 = Discordo totalmente | 2 = Discordo | 3 = Neutro | 4 = Concordo | 5 = Concordo totalmente
1. A oficina foi interessante e me motivou a participar.
2. A explicação foi clara e facilitou o entendimento.
3. Consegui acompanhar bem as etapas da atividade.
4. O tempo foi suficiente para testar e experimentar o robô.
5. Senti que tive espaço para perguntar e interagir durante a oficina.
6. A montagem do robô foi fácil de entender.
7. O robô funcionou corretamente durante os testes.
8. Programar com o mBlock foi simples e intuitivo.
9. Aprendi como os sensores influenciam o comportamento do robô.
10. Entendi melhor como funcionam comandos de lógica e repetição.
11. Acredito que realizar a programação escrita do robô seria mais complicado do que usando o MBlock.
12. Me sinto mais confiante para montar e programar robôs.
13. Gostaria de participar de mais atividades como essa.
14. Me interessei em aprender mais sobre Arduino e eletrônica.
15. Usar de conceitos práticos como robô me ajudou a ter uma concepção melhor da teoria.
16. Sinto que fixo mais o conteúdo em aulas com atividades práticas.
17. Aprendo mais com exemplos práticos do que apenas com teoria.

Perguntas Abertas
- O que você mais gostou na oficina?
- Teve alguma parte difícil ou confusa? Qual?
- Gostaria do uso dessa ferramenta na sua sala de aula em outras matérias? Porque?

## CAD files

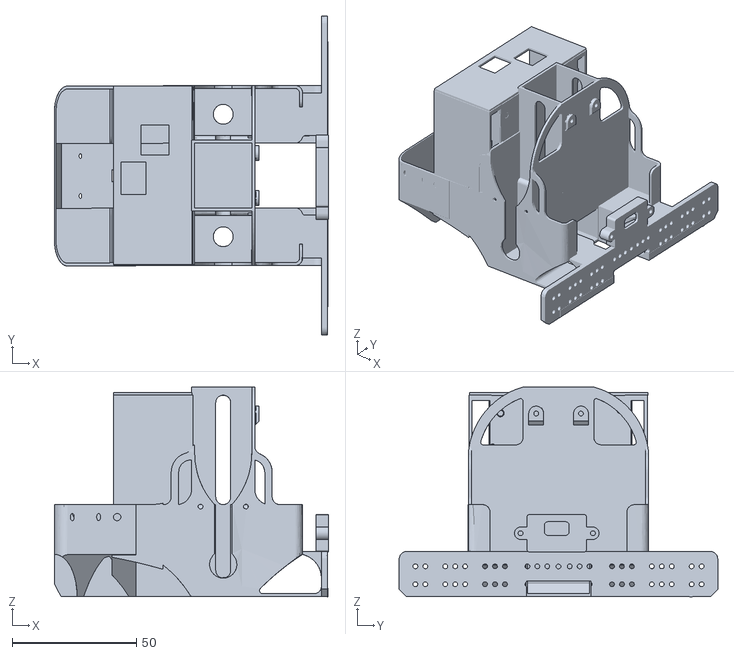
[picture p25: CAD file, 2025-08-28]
Arquivos_Impressao_3D/B.E.M.O.stl
110.1 x 128.0 x 84.3

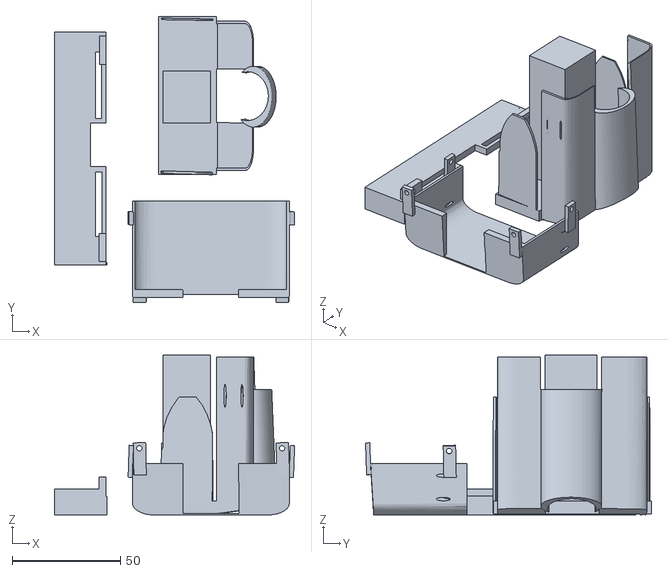
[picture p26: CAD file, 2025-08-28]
Arquivos_Impressao_3D/Modulo Base.stl
110.8 x 132.0 x 73.8

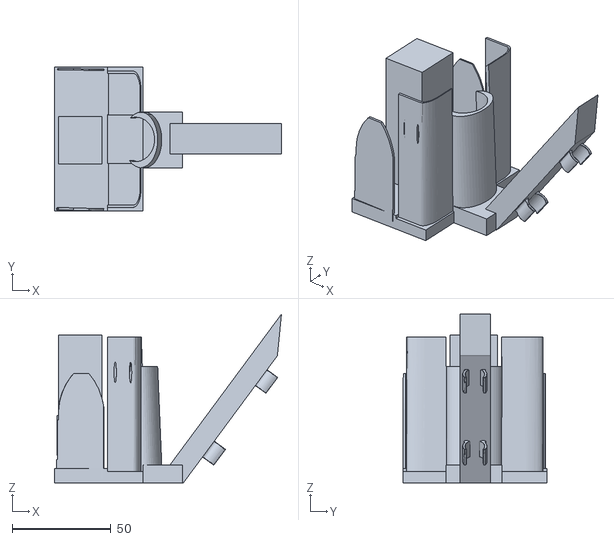
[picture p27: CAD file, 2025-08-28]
Arquivos_Impressao_3D/Modulo Arte.stl
115.0 x 73.1 x 85.6

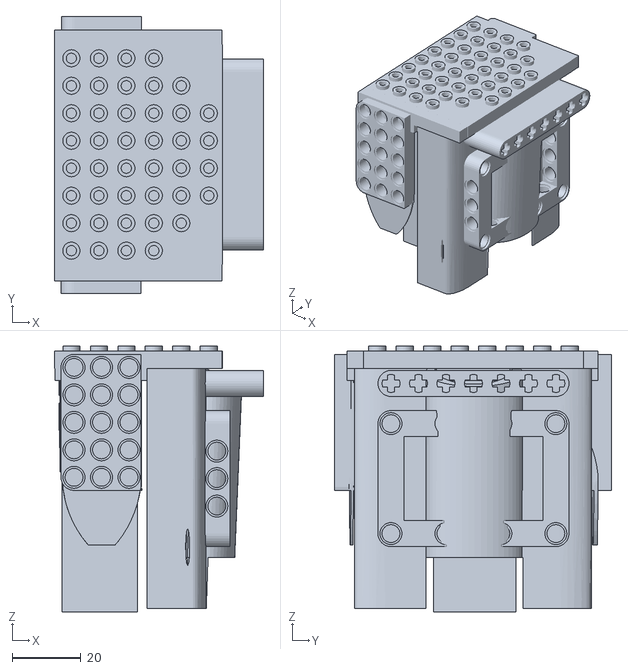
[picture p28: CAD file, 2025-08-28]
Arquivos_Impressao_3D/Modulo Lego.stl
60.9 x 80.6 x 77.4

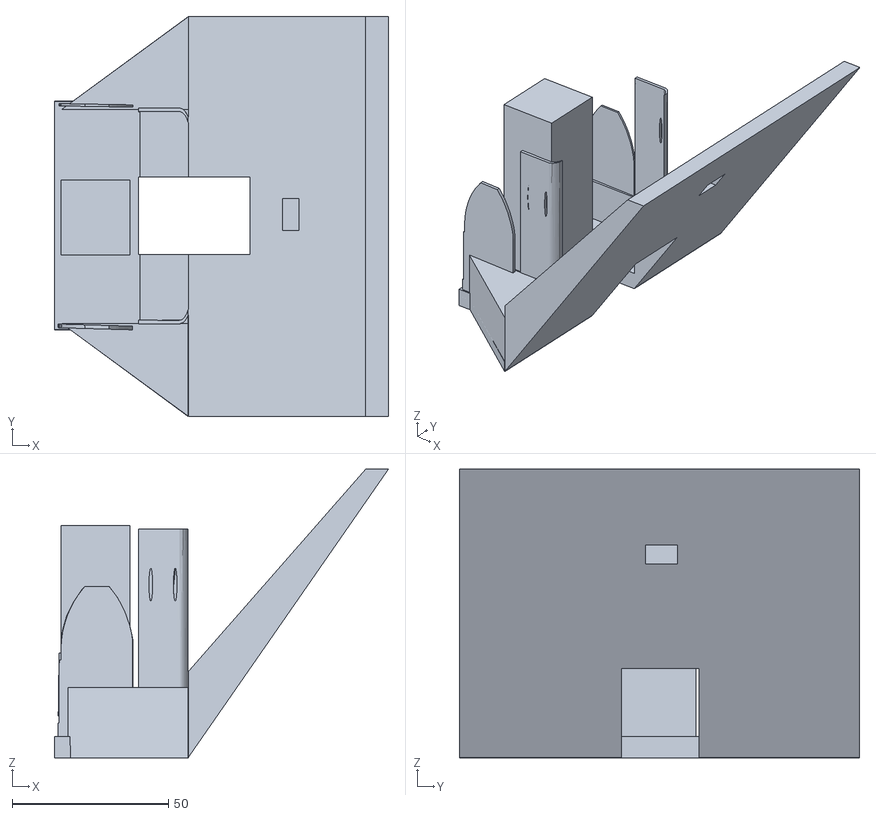
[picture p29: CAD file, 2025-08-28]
Arquivos_Impressao_3D/Modulo Sumo.stl
106.8 x 128.0 x 92.3
